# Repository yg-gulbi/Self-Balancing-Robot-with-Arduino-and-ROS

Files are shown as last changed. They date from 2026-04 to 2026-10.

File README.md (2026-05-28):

# Arduino-ROS Self-Balancing Robot

English | [한국어](README.ko.md)

This repository is my self-balancing robot project. The real robot was controlled on Arduino, and I used ROS/Gazebo for simulation, tuning, SLAM, and navigation experiments.

This is a portfolio reconstruction of the project rather than a perfectly chronological original development repository. I recovered and organized the final Arduino firmware, ROS/Gazebo workspace, hardware notes, media, CAD-related assets, results, and limitations so the project can be reviewed from evidence instead of scattered raw files.

The main result is a physical two-wheeled robot that balanced for about 1 hour and drove through a 10 m hallway and obstacle course under Arduino control. On the ROS side, I built Gazebo control, navigation, SLAM map-generation, PID tuning, and Arduino-to-ROS bridge workflows. The sim-to-real bridge is documented as a command-layer transfer: high-level motion intent is separated from the balance and safety layer instead of driving the robot directly.

## Interview Quick Read

- One-line summary: this is a two-wheeled self-balancing robot project where I isolated real hardware instability into sensor, communication, control-loop, and safety-logic problems, then stabilized the system step by step.
- My role: Arduino firmware, control algorithm design, IMU/encoder/ODrive/RC receiver integration, ROS/Gazebo simulation, SLAM/navigation workflows, and hardware debugging.
- Key debugging story: I moved away from IMU-integration-based speed estimation after finding tilt contamination, switched to wheel-encoder feedback, and added filtering/deadband/engage persistence for noisy RC PWM input. I also added current clamps and tilt cutoff so abnormal states would not become unsafe motor commands.
- Verification style: I split the system into small test paths such as `receiver_pwm_test`, `hall_sensor_test`, `odrive_receiver_test`, and `motor_current_test`, then integrated them back into the full robot.
- What to notice: the value of this project is not only the final demo, but the way unstable real hardware was made testable, safer, and repeatable.

<p align="center">
  Physical hallway balancing demo
</p>

## Result Snapshot

| Area | Result |
| --- | --- |
| Physical balance duration | About 1 hour standing balance |
| Physical driving | 10 m hallway driving and obstacle-course driving |
| Physical safety limit | Motor command cutoff at `30 deg`, chosen because the protection bracket touches the floor at about `28 deg` |
| ODrive current limit | `+/-8 A` command clamp in firmware |
| RC signal handling | `+/-50 us` deadband, throttle/steering filter alpha `0.4`, engage filter alpha `0.02` |
| Arduino-to-ROS bridge | `/imu`, `/odom`, and `cmd_vel` checked with `rostopic echo` |
| ROS/Gazebo navigation | Robot motion through the ROS navigation command path was checked and captured in the depth-navigation simulation |
| ROS/Gazebo SLAM | Map generation was checked in the SLAM workflow |

## Core Result

<p align="center">
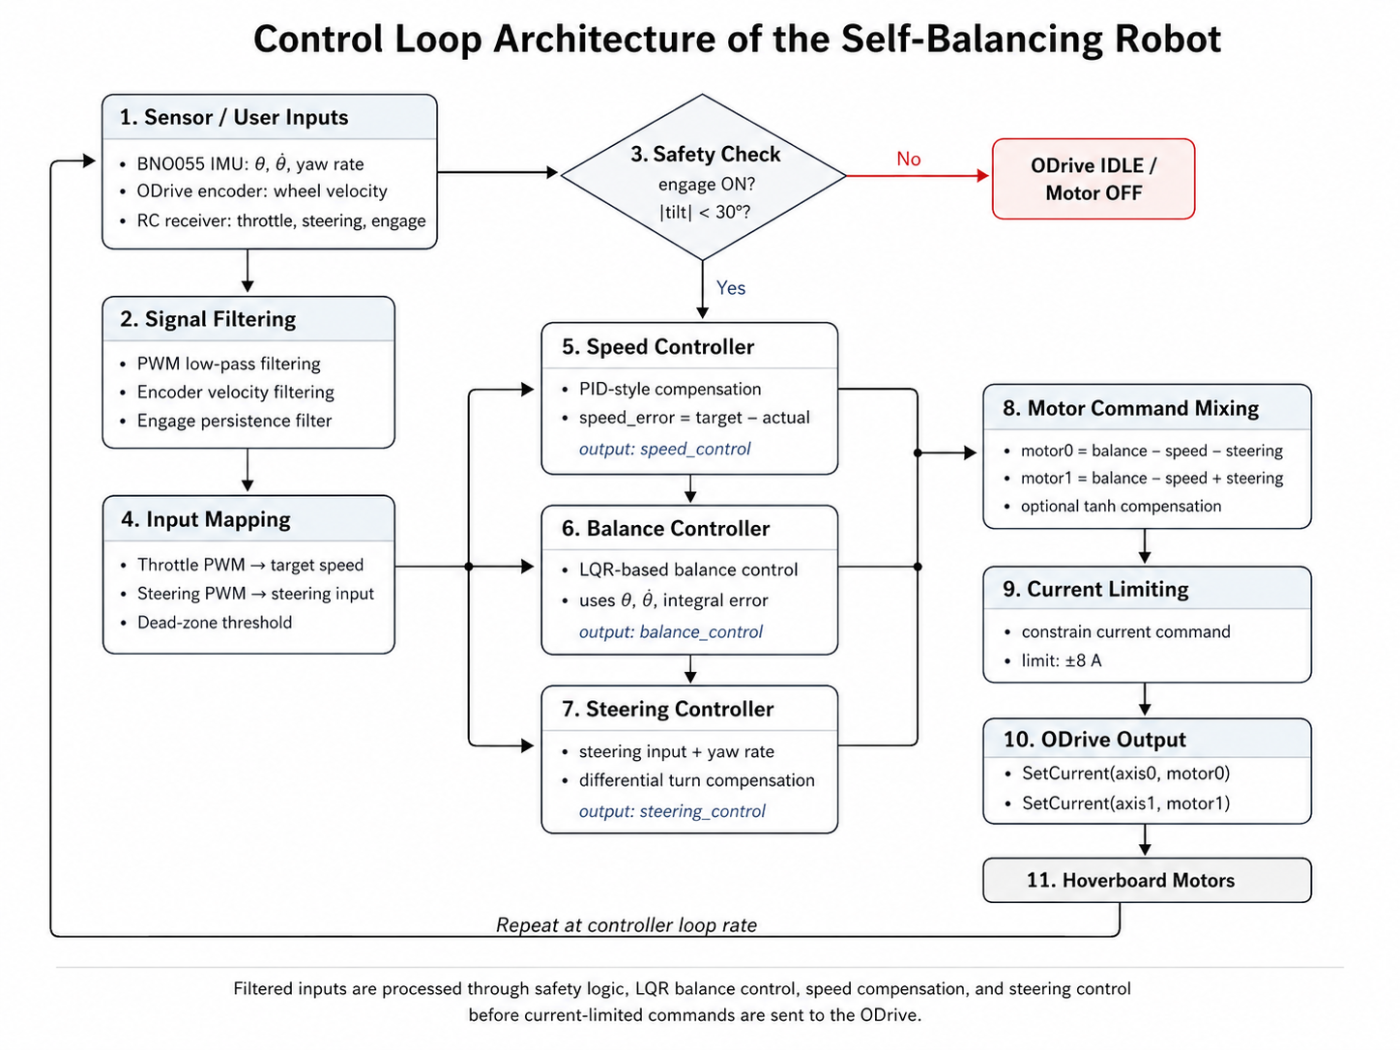
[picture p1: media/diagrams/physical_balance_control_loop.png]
Physical balance control loop
  
</p>

The Arduino closes the balance loop locally. RC intent, IMU tilt and yaw feedback, wheel-speed feedback, safety checks, and ODrive current commands are all combined into one real-time control path.

| Control layer | What it does |
| --- | --- |
| Balance | Body angle and angular velocity generate the main stabilizing current term. |
| Motion | RC throttle becomes a target speed, then shifts the balance point so the robot can drive while staying upright. |
| Safety | PWM filtering, engage persistence, tilt cutoff, and current limiting prevent bad states from reaching the motors. |

Start here: [physical balance control algorithm](firmware/physical_balance_controller/control_algorithm.md) and [troubleshooting summary](docs/troubleshooting.md).

## Project Scope

| Area | Status | Where to look |
| --- | --- | --- |
| Physical self-balancing and RC driving | Completed | [physical_balance_controller.ino](firmware/physical_balance_controller/physical_balance_controller.ino), [hallway demo](media/hero/physical_balance_hallway.gif) |
| ROS/Gazebo balance simulation | Completed | [balance_robot_control](ros_ws/src/balance_robot_control), [balance_robot_gazebo](ros_ws/src/balance_robot_gazebo) |
| Simulation navigation pipeline | Completed | [navigation](ros_ws/src/navigation), [balance_robot_workflows](ros_ws/src/balance_robot_workflows), [depth-navigation capture](media/process/simulation_depth_navigation_views.png) |
| Simulation SLAM/navigation workflow | Completed in simulation | [balance_robot_workflows](ros_ws/src/balance_robot_workflows), [results and limitations](docs/results-and-limitations.md) |
| Sim2Real bridge | Documented | [sim-to-real bridge](docs/sim2real.md), [results and limitations](docs/results-and-limitations.md) |
| Arduino-to-ROS bridge tests | Completed | [rc_to_ros_cmd_vel_bridge.ino](firmware/testers/rc_to_ros_cmd_vel_bridge.ino), [physical_balance_controller_ros.ino](firmware/physical_balance_controller_ros/physical_balance_controller_ros.ino) |
| Real-world ROS SLAM/navigation | Integration experiments | [real-world integration archive](archive/ros_experiments/real_world_integration), [results and limitations](docs/results-and-limitations.md) |

## Sim2Real Bridge

<p align="center">
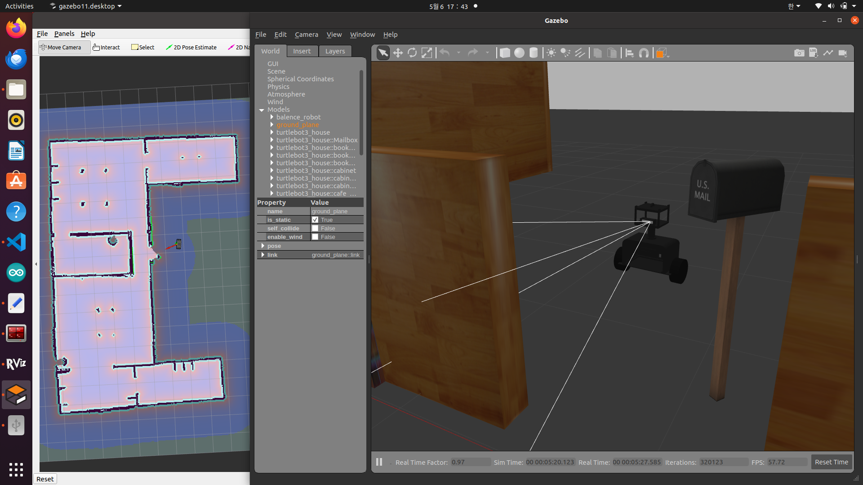
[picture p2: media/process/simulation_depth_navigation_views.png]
ROS/Gazebo depth-navigation simulation with RViz map and Gazebo robot model
  
</p>

<p align="center">
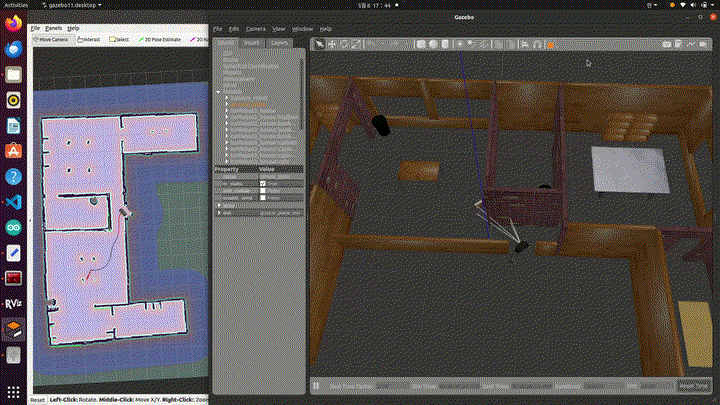
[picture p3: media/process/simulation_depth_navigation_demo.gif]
ROS/Gazebo depth-navigation simulation GIF preview
  
</p>

<p align="center">
  Full clip: <a href="media/process/simulation_depth_navigation_demo.webm">WebM download</a>
</p>

The simulation used the same two-wheeled, 3D-printed design direction as the physical robot, but the key transfer was the command structure. A high-level command is treated as motion intent first; the balance and safety layer decides what can safely reach the robot.

| Transfer point | Simulation side | Physical side |
| --- | --- | --- |
| Command path | `move_base -> /before_vel -> balance_robot_control -> /cmd_vel` | RC or ROS-side intent -> Arduino balance/safety loop -> ODrive current commands |
| Robot state | Gazebo `/imu`, `/odom`, scan/depth data, RViz map/navigation state | BNO055 IMU, ODrive feedback, RC PWM, Gemini 330 integration traces |
| What was proven | Navigation command routing, depth-navigation workflow, SLAM/map-generation workflow | Real balancing, RC driving, current limiting, tilt cutoff, and staged safety tuning |

This is why I describe the project as a sim-to-real bridge, not as finished physical autonomous navigation. The bridge is the transfer of robot design, command layering, and safety boundaries from simulation work into the real Arduino-controlled robot. See [docs/sim2real.md](docs/sim2real.md) for the detailed breakdown.

## System At A Glance

<table>
  <tr>
    <td width="50%">
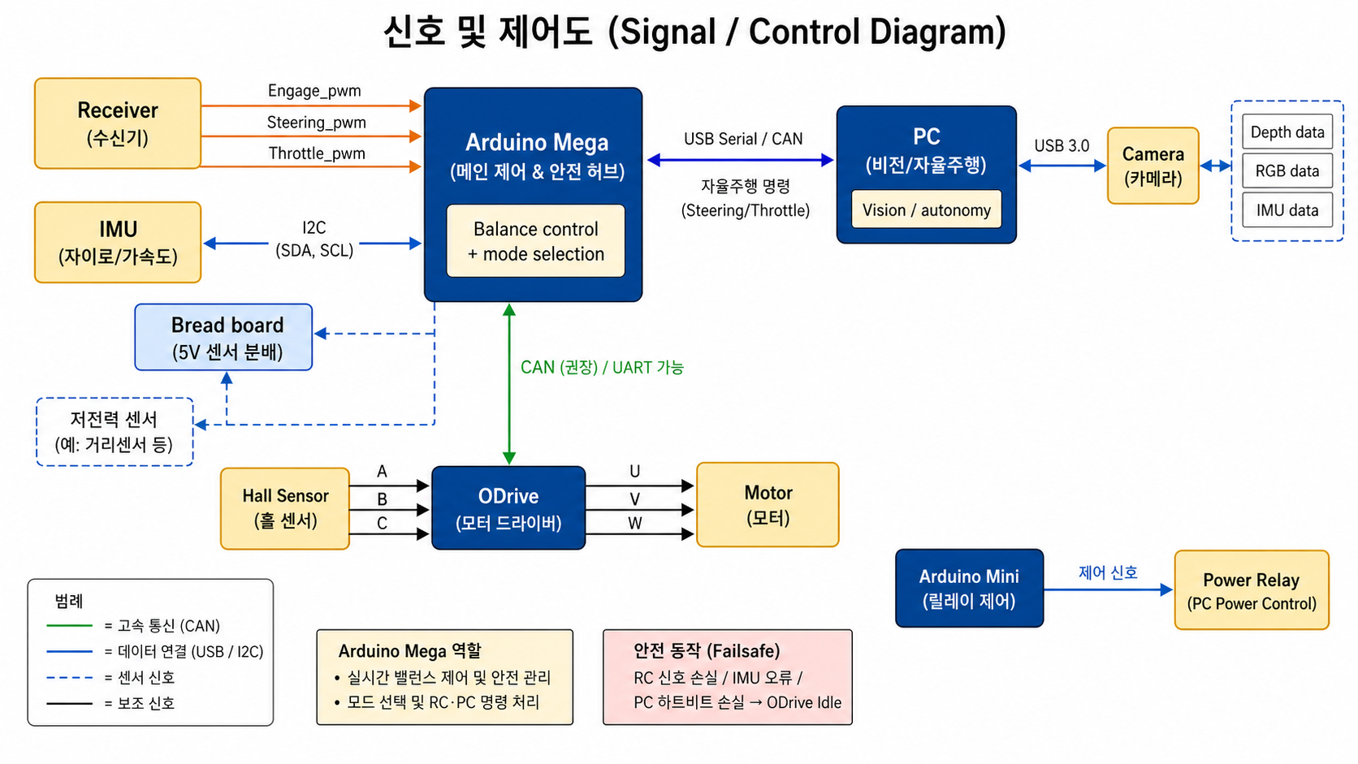
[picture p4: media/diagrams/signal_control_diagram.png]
Signal / Control Diagram
      
    </td>
    <td width="50%">
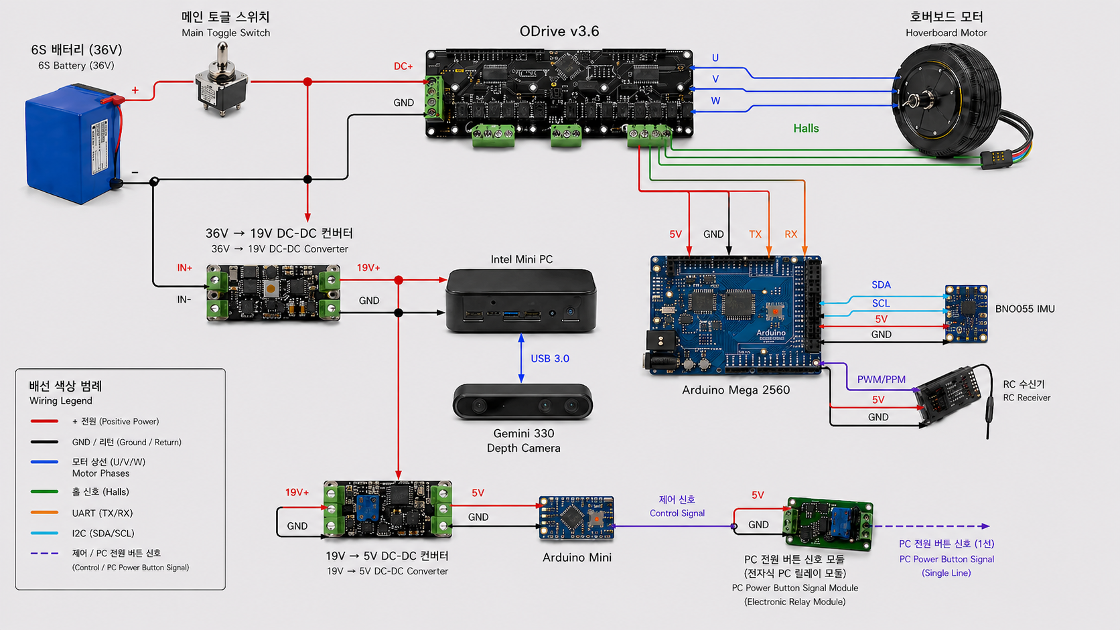
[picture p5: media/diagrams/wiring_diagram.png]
Wiring Diagram
      
    </td>
  </tr>
  <tr>
    <td valign="top">
      <strong>Control responsibility</strong><br>
      Arduino owns the real-time balance loop. ROS-side commands are treated as higher-level inputs, not direct motor authority.
    </td>
    <td valign="top">
      <strong>Hardware wiring</strong><br>
      36V power, ODrive, Arduino, BNO055, FrSky receiver, onboard PC, Gemini 330 camera, auxiliary electronics, and motors are summarized in one view.
    </td>
  </tr>
</table>

Main physical hardware: Arduino Mega 2560, BNO055 IMU, ODrive 3.6, FrSky Taranis Q X7 + X8R, Orbbec Gemini 330, dual hall-sensor BLDC hub motors, 36V battery, onboard mini PC, DC-DC converters, auxiliary Arduino, and relay module.

For the consolidated hardware explanation, see [docs/hardware.md](docs/hardware.md). For the build story and research context, see [docs/development-process.md](docs/development-process.md).

## Repository Layout

| Path | Purpose |
| --- | --- |
| `firmware/` | Arduino firmware, physical controller, and tester sketches |
| `ros_ws/` | Main ROS workspace for simulation, navigation, SLAM workflow, tuning code, and recovered actual-robot STL visuals |
| `mechanical/` | GitHub-ready 3D print, CAD, and sensor-head frame files copied from the original modeling archive |
| `docs/` | Focused portfolio docs: hardware, development process, Sim2Real, troubleshooting, and results |
| `media/` | Lightweight public GIFs, photos, and diagrams |
| `archive/` | Older experiments and recovered context that should not be the first place to read |

## Why The Title Includes Arduino And ROS

I kept `Arduino-ROS` in the title because the project really used both sides. Arduino handled the physical robot and some ROS publishing tests, while ROS/Gazebo handled simulation, visualization, SLAM and navigation workflows, and integration experiments.

| Sketch | ROS role | Published data |
| --- | --- | --- |
| [physical_balance_controller_ros.ino](firmware/physical_balance_controller_ros/physical_balance_controller_ros.ino) | ROS-enabled physical controller variant | `/imu`, `/odom` |
| [rc_to_ros_cmd_vel_bridge.ino](firmware/testers/rc_to_ros_cmd_vel_bridge.ino) | RC receiver to ROS command bridge | `cmd_vel` |
| [experimental_balance_controller_imu_ros.ino](archive/arduino_firmware/experimental_balance_controller_imu_ros.ino) | Archived IMU publisher experiment | `/imu` |
| [legacy_balance_controller.ino](archive/arduino_firmware/legacy_balance_controller.ino) | Archived ROS publisher trace | `/imu`, `/odom` publisher logic |

## ROS Workspace

This repository keeps the custom ROS packages, but it does not vendor every third-party dependency snapshot. Extra packages such as `rtabmap_ros`, `OrbbecSDK_ROS1`, `depthimage_to_laserscan`, `rosserial`, and TurtleBot3/Realsense simulation assets should be placed under `ros_ws/src/third_party/` when reproducing historical workflows.

```bash
cd ros_ws
catkin_make
source devel/setup.bash
roslaunch robot_bringup robot_remote_lidar.launch
```

Navigation-oriented simulation workflow:

```bash
roslaunch balance_robot_workflows robot_navigation_lidar.launch
```

Use [ros_ws/README.md](ros_ws/README.md) for workspace usage and [balance_robot_control/README.md](ros_ws/src/balance_robot_control/README.md) for the controller package layout.
The recovered body STL assets from the actual robot-based simulation baseline now live under [ros_ws/src/balance_robot_description/stl](ros_ws/src/balance_robot_description/stl), with notes in [docs/simulation-assets.md](docs/simulation-assets.md). The fabrication-oriented CAD and 3D-print files are organized separately in [mechanical](mechanical).

## Demo Media

- [Physical hallway balancing GIF](media/hero/physical_balance_hallway.gif)
- [Physical obstacle-course balancing GIF](media/demos/physical_balance_obstacle_course.gif)
- [ROS/Gazebo depth-navigation still](media/process/simulation_depth_navigation_views.png)
- [ROS/Gazebo depth-navigation GIF preview](media/process/simulation_depth_navigation_demo.gif)
- [ROS/Gazebo depth-navigation WebM clip](media/process/simulation_depth_navigation_demo.webm)
- [Robot-focused hallway still](media/demos/hallway_robot_only.jpg)
- [Open-front hardware photo](media/hardware/robot_open_front.png)

I did not put the full original phone MP4 files in the repo. Instead, I kept lightweight GIFs, still images, and one compact WebM simulation clip so the repository stays easier to browse. The navigation demo now includes a GitHub-friendly GIF preview plus the original WebM clip for higher-quality playback.

## Read Next

1. [Physical controller](firmware/physical_balance_controller/README.md): main Arduino firmware for the real balancing robot.
2. [Control algorithm](firmware/physical_balance_controller/control_algorithm.md): how RC input, IMU feedback, wheel speed, safety, and ODrive current control fit together.
3. [Hardware](docs/hardware.md): physical components, wiring, power flow, and layout interpretation.
4. [Mechanical 3D files](mechanical): printable frame parts, editable CAD exports, and sensor-head structure files.
5. [Development process](docs/development-process.md): build timeline, subsystem bring-up, and research decisions.
6. [Sim2Real bridge](docs/sim2real.md): how the ROS/Gazebo workflow and physical Arduino robot were connected without overstating physical autonomy.
7. [Troubleshooting summary](docs/troubleshooting.md): why filtering, safety gating, ODrive isolation, and staged tuning were needed.
8. [Results and limits](docs/results-and-limitations.md): measured project results, code-defined settings, and remaining limits.

## Limitations

- This repository is organized for portfolio review, so the commit history is not a complete record of every original hardware experiment.
- Full end-to-end autonomous ROS navigation on the physical balancing robot remains future work.
- Some older code remains in `archive/` because it still helps explain how the project evolved.
- Third-party ROS dependencies are not vendored into this repository.
- Raw process files, chat exports, and full-length videos were summarized or replaced with lighter public assets.
- Code is MIT-licensed. Media, photos, demo captures, CAD files, and 3D-print assets are included for portfolio documentation; see [LICENSE](LICENSE).

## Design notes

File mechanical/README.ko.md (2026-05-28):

# 기구 3D 파일

[English](README.md) | 한국어

이 폴더는 로봇 골격, 출력용 body part, sensor-head 구조를 GitHub에서
찾아보기 쉽게 정리한 3D 파일 모음입니다.

파일은 2026-05-11에 로컬 모델링 archive에서 가져왔습니다.

- `D:\06_3D_모델링\SLDPRT\balancing robot`
- `D:\06_3D_모델링\SLDPRT\new_balencerobot`

CAD assembly와 과거 작업 흔적을 추적하기 쉽도록 원본 파일명은 가능한 한
그대로 보존했습니다. `balanicng`, `balence`처럼 오타처럼 보이는 이름도
원본 파일명과 연결되도록 일부러 바꾸지 않았습니다.

## 폴더 역할

| 경로 | 내용 | 용도 |
| --- | --- | --- |
| `print_ready/` | main body package, side plate, board plate, battery plate, breadboard plate, Intel plate, resistor plate의 STL 및 CATPart export | 3D printing reference 및 수정 가능한 part source |
| `head_sensor_mount/` | neck, inner neck, head versions, Gemini case file(`gemini335_case`), LiDAR case의 CATIA/STL 파일 | sensor-head와 상단 frame 참고 |
| `new_balancerobot_concept/` | 작은 SolidWorks concept assembly, SLDPRT part, STL, STEP export | 이후 concept/reference geometry |

## 시각 참고 이미지

아래 eDrawings 이미지는 source CAD의 기준이 된 `balancing robot_ver4`
assembly view입니다.

<table>
  <tr>
    <td width="50%">
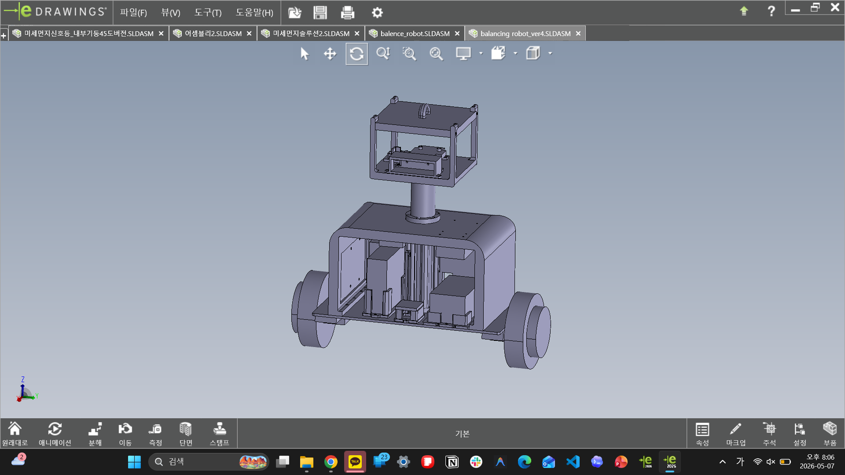
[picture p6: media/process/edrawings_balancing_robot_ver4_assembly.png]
Balancing robot ver4 eDrawings assembly view
      
    </td>
    <td width="50%">
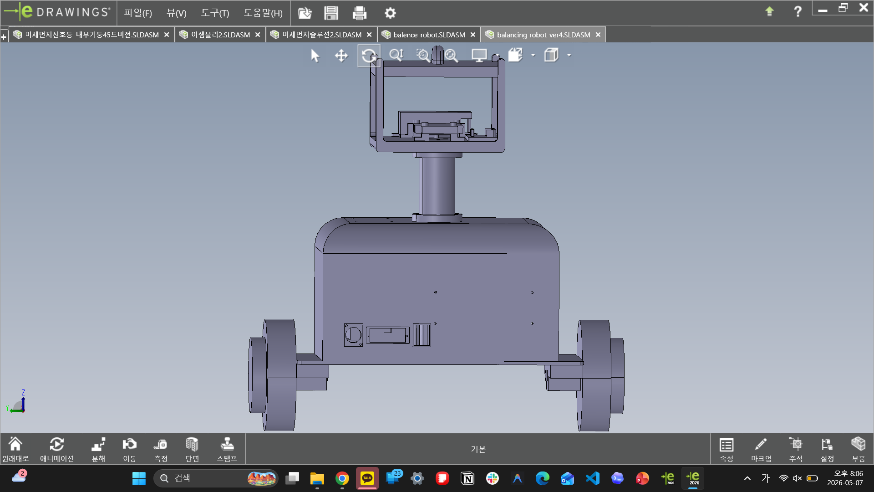
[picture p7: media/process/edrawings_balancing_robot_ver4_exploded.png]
Balancing robot ver4 eDrawings exploded view
      
    </td>
  </tr>
</table>

## ROS 모델과의 관계

현재 ROS/Gazebo package는 `ros_ws/src/balance_robot_description/stl/`의
정리된 mesh set을 사용합니다. 그쪽 파일은 URDF/Xacro에서 참조하기 쉽도록
짧은 이름으로 정리한 simulation-friendly visual asset입니다.

실제 제작용 source file이나 physical frame design을 확인할 때는 이
`mechanical/` 폴더를 보면 됩니다. URDF/Xacro visual을 수정할 때는 ROS
package 안의 `stl/` 폴더를 기준으로 보는 것이 좋습니다.

## 출력 전 메모

- 출력 전 slicer에서 scale, orientation, wall thickness, hole tolerance를
  다시 확인해야 합니다.
- 특정 printer용 G-code는 넣지 않았습니다. printer, nozzle, material,
  layer height에 맞춰 새로 생성하는 편이 안전합니다.
- 현재 ROS 모델의 collision과 inertia는 의도적으로 단순화되어 있습니다.
  이 상세 mesh를 simulation physics에 바로 넣으려면 mass, origin,
  collision assumption을 먼저 검토해야 합니다.

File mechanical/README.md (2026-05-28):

# Mechanical 3D Files

[한국어](README.ko.md) | English

This folder keeps the GitHub-facing 3D files for the robot frame, printable
body parts, and sensor-head structure.

The files were copied from the local modeling archive on 2026-05-11:

- `D:\06_3D_모델링\SLDPRT\balancing robot`
- `D:\06_3D_모델링\SLDPRT\new_balencerobot`

The original file names are preserved where possible so CAD assemblies and
historical references are easier to trace. A few misspellings such as
`balanicng` and `balence` are kept intentionally because they came from the
original project files.

## Folder Roles

| Path | Contents | Use |
| --- | --- | --- |
| `print_ready/` | STL and CATPart exports for the main body package, side plates, board plate, battery plate, breadboard plate, Intel plate, and resistor plate | 3D-print reference and editable part source |
| `head_sensor_mount/` | CATIA/STL files for the neck, inner neck, head versions, Gemini case file (`gemini335_case`), and LiDAR case | Sensor-head and upper frame reference |
| `new_balancerobot_concept/` | Smaller SolidWorks concept assembly, SLDPRT parts, STL, and STEP exports | Later concept/reference geometry |

## Visual Reference

These eDrawings views show the `balancing robot_ver4` assembly that the source
CAD files came from.

<table>
  <tr>
    <td width="50%">
      Balancing robot ver4 eDrawings assembly view
    </td>
    <td width="50%">
      Balancing robot ver4 eDrawings exploded view
    </td>
  </tr>
</table>

## How This Relates To ROS

The active ROS/Gazebo package still uses the cleaned mesh set in
`ros_ws/src/balance_robot_description/stl/`. Those files are short-name,
simulation-friendly visual assets.

Use this `mechanical/` folder when you need the fabrication-oriented source
files or want to inspect the physical frame design. Use the ROS `stl/` folder
when editing URDF/Xacro visuals.

## Printing Notes

- Re-check scale, orientation, wall thickness, and hole tolerances in your
  slicer before printing.
- No printer-specific G-code is included here. Generate fresh G-code for the
  target printer, nozzle, material, and layer height.
- Collision and inertia in the active ROS models are intentionally simplified;
  these detailed meshes should not be dropped into simulation physics without
  reviewing mass, origin, and collision assumptions.

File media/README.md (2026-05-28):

# Media

This directory stores only the media that I wanted to keep in the public repository, with cleaner filenames.

## Structure

- `hero/`: README hero asset
- `demos/`: supporting physical demo GIFs and stills
- `hardware/`: hardware photos used to support the public device story
- `process/`: build-process images such as bench tests, tethered practice, CAD screenshots, and simulation captures
- `diagrams/`: canonical GitHub-facing architecture diagrams used across the docs
- `links.md`: policy for full-length original clips

## Canonical Diagram Assets

- `diagrams/wiring_diagram.png`: main public hardware, power, and wiring overview
- `diagrams/signal_control_diagram.png`: main public control-responsibility and autonomy-flow overview
- `diagrams/physical_balance_control_loop.png`: main physical balance-control loop diagram for the Arduino firmware

## Featured Simulation Assets

- `process/simulation_depth_navigation_views.png`: public still showing RViz map/navigation state beside the Gazebo depth-camera robot model
- `process/simulation_depth_navigation_demo.webm`: compact WebM clip of the depth-navigation simulation workflow

## Featured Mechanical Assets

- `process/edrawings_balancing_robot_ver4_assembly.png`: eDrawings assembly view of the mechanical robot frame
- `process/edrawings_balancing_robot_ver4_exploded.png`: eDrawings exploded/reference view of the same assembly

## Naming Rules

- Do not store raw phone or chat-export filenames here.
- Do not store full original MP4 clips here.
- Keep only lightweight GIFs, stills, compact WebM clips, and visuals that are easy to show publicly.

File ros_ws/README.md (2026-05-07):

# ROS Workspace Guide

This folder is the main ROS workspace for the self-balancing robot project.
It shows how the simulation, balancing controller, SLAM, and navigation launch
files fit together.

The physical robot's fast balance loop runs on Arduino. In this workspace, ROS
is used for Gazebo simulation, workflow orchestration, navigation, SLAM, RViz,
and controller tuning experiments.

## Main Command Flow

The key idea is that high-level commands do not drive the balancing robot
directly.

```text
teleop or move_base
  -> /before_vel
  -> balance_robot_control
  -> /cmd_vel
  -> Gazebo robot
```

`/before_vel` is the desired motion command. The balancing controller converts
that command into a final `/cmd_vel` that respects the robot's pitch, velocity,
and steering behavior.

## Environment

This workspace targets a ROS 1 `catkin` setup, most likely Ubuntu + ROS Noetic
or a similar ROS 1 distribution.

Expected tools and packages:

- `catkin_make`
- `gazebo_ros`
- `xacro`
- `robot_state_publisher`
- `joint_state_publisher`
- `map_server`
- `amcl`
- `move_base`
- `dynamic_reconfigure`
- `rqt_reconfigure`
- `OrbbecSDK_ROS1` for physical Orbbec Gemini 330 camera integration traces
- `rtabmap_ros` or `rtabmap_launch` for depth SLAM workflows
- `depthimage_to_laserscan` for depth-camera navigation workflows
- `realsense_ros_gazebo` for historical D435-style Gazebo depth simulation assets

Third-party packages that are not part of this repository should be placed
under `src/third_party/` or installed through the normal ROS package manager.

## Build

From this folder:

```bash
cd ros_ws
catkin_make
source devel/setup.bash
```

If you open a new terminal, run `source devel/setup.bash` again before launching
anything from this workspace.

## Quick Start

These are the launch files I would start with.

| Goal | Command | Use this when |
| --- | --- | --- |
| Show the LiDAR robot model only | `roslaunch robot_bringup robot_remote_lidar.launch` | You want to inspect URDF, TF, and robot state publishing |
| Show the depth-camera robot model only | `roslaunch robot_bringup robot_remote_depth.launch` | You want to inspect the depth-camera version of the robot |
| Run LiDAR balance simulation | `roslaunch balance_robot_workflows robot_control_lidar.launch` | You want the simplest Gazebo balancing-controller demo |
| Run depth balance simulation | `roslaunch balance_robot_workflows robot_control_depth.launch` | You want the depth-camera robot model with the balancing controller |
| Tune PID gains manually | `roslaunch balance_robot_workflows robot_control_lidar_pid_tuning.launch` | You want Gazebo plus `rqt_reconfigure` for live controller tuning |
| Run LiDAR navigation simulation | `roslaunch balance_robot_workflows robot_navigation_lidar.launch` | You want map localization, `move_base`, RViz, and balance-aware command remapping |
| Run depth navigation simulation | `roslaunch balance_robot_workflows robot_navigation_depth.launch` | You want depth data projected into a scan-like navigation pipeline |
| Run depth SLAM simulation | `roslaunch balance_robot_workflows robot_slam_depth.launch` | You want the RGB-D/RTAB-Map SLAM experiment |

## Actual Robot Geometry Assets

The default model still uses the simplified box body so the historical control
and navigation setup stays unchanged. If you want the recovered STL visuals
from the actual robot-based simulation archive, add
`use_actual_stl_assembly:=true` to bringup, Gazebo, navigation, or workflow
launch commands.

Example:

```bash
roslaunch balance_robot_workflows robot_navigation_depth.launch use_actual_stl_assembly:=true
```

The STL files live in `src/balance_robot_description/stl/`. They change visual
appearance only; collision and inertia remain simple on purpose. See
[`src/balance_robot_description/README.md`](src/balance_robot_description/README.md)
and [`../docs/simulation-assets.md`](../docs/simulation-assets.md).

## Recommended Execution Order

For a first review, run the workspace in this order:

1. `roslaunch balance_robot_workflows robot_control_lidar.launch`
2. `rosrun balance_robot_control teleop_before_vel.py`
3. `roslaunch balance_robot_workflows robot_navigation_lidar.launch`
4. `roslaunch balance_robot_workflows robot_control_lidar_pid_tuning.launch`
5. `roslaunch balance_robot_workflows robot_slam_depth.launch`

Use the first command as the default control demo. Move on to navigation after the control path is working. Use PID tuning when you want to inspect gain behavior. Leave SLAM for last because it depends on the most external RGB-D packages.

## Manual Driving

For manual command testing, start a control workflow first:

```bash
roslaunch balance_robot_workflows robot_control_lidar.launch
```

Then publish desired motion into `/before_vel`. The helper script is:

```bash
rosrun balance_robot_control teleop_before_vel.py
```

The important detail is that manual teleop should target `/before_vel`, not
`/cmd_vel`. The controller owns `/cmd_vel`.

## Navigation Workflow

The navigation stack is adapted from a normal mobile-robot setup, but the output
topic is remapped.

Normal robot:

```text
move_base -> /cmd_vel
```

This balancing robot:

```text
move_base -> /before_vel -> balance_robot_control -> /cmd_vel
```

Recommended launch:

```bash
roslaunch balance_robot_workflows robot_navigation_lidar.launch
```

What this starts:

- Gazebo with the LiDAR robot model
- the balance-aware controller
- map server
- AMCL localization
- `move_base`
- RViz

In RViz, use `2D Pose Estimate` for the initial pose and `2D Nav Goal` for a
target. The planner output is routed through the balance controller before the
robot receives a final velocity command.

## SLAM Workflow

Recommended launch:

```bash
roslaunch balance_robot_workflows robot_slam_depth.launch
```

This starts the depth-camera robot workflow and RTAB-Map-related launch logic.
This path depends on external RGB-D SLAM packages, so it is the most likely
workflow to require extra package installation before it runs cleanly.

## PID Tuning Workflow

Manual tuning entrypoint:

```bash
roslaunch balance_robot_workflows robot_control_lidar_pid_tuning.launch
```

The tuning flow uses `dynamic_reconfigure`, so gains can be edited from
`rqt_reconfigure`.

The control package also keeps automated tuning experiments:

- `src/balance_robot_control/src/tuning_tools/pid_bayes_optimizer.py`
- `src/balance_robot_control/src/tuning_tools/pid_loop_test_runner.py`
- `src/balance_robot_control/src/tuning_tools/pid_reconfigure_client.py`

These scripts show that I tried repeated controller-evaluation and tuning
experiments. I do not present them as a fully solved production auto-tuning
system.

## Topic Contract

| Topic | Direction | Meaning |
| --- | --- | --- |
| `/before_vel` | input to `balance_robot_control` | Desired high-level motion from teleop or navigation |
| `/cmd_vel` | output from `balance_robot_control` | Final balance-aware command sent to the simulated robot |
| `/imu` | input to controller | Simulated robot attitude and angular velocity |
| `/odom` | input to controller/navigation | Simulated odometry feedback |
| `/scan` | input to navigation | LiDAR or depth-projected scan data |
| `/map` | input to navigation/RViz | Static map from `map_server` or SLAM output |

## Package Map

| Folder | ROS package name | Role |
| --- | --- | --- |
| `src/balance_robot_bringup/` | `robot_bringup` | Robot model bringup and description launch entrypoints |
| `src/balance_robot_description/` | `robot_description` | URDF/Xacro definitions plus recovered actual-robot STL body visuals |
| `src/balance_robot_gazebo/` | `robot_gazebo` | Gazebo worlds, robot spawn files, and controller launch files |
| `src/balance_robot_control/` | `balance_robot_control` | Balance-aware control nodes, PID tuning, and tuning automation helpers |
| `src/balance_robot_workflows/` | `balance_robot_workflows` | Scenario-level launch files for control, tuning, navigation, and SLAM |
| `src/navigation/` | `navigation` | `move_base`, AMCL, maps, planner parameters, and RViz configs |
| `src/third_party/` | external packages | Optional location for dependencies not committed to this repo |

## If You Want To Read The ROS Side Quickly

I would read the ROS side in this order:

1. [`src/balance_robot_workflows/README.md`](src/balance_robot_workflows/README.md)
2. [`src/balance_robot_control/README.md`](src/balance_robot_control/README.md)
3. [`src/balance_robot_description/README.md`](src/balance_robot_description/README.md)
4. [`src/navigation/README.md`](src/navigation/README.md)
5. [`../docs/results-and-limitations.md`](../docs/results-and-limitations.md)

## Troubleshooting

If a package cannot be found, source the workspace again:

```bash
source devel/setup.bash
rospack find balance_robot_control
```

If Gazebo opens but the robot does not move, check that the controller is
running and that `/before_vel` is receiving commands:

```bash
rostopic list
rostopic echo /before_vel
rostopic echo /cmd_vel
rosnode list
```

If navigation does not move the robot, confirm that `move_base` is publishing
to `/before_vel` and that `balance_robot_control` is republishing to `/cmd_vel`.

If SLAM launch fails, install or provide the missing RGB-D packages first. The
most likely missing packages are `rtabmap_ros`, `rtabmap_launch`, camera plugin
packages, or depth-to-scan conversion packages.

## Scope And Limits

- This workspace is strongest on the simulation and integration side.
- The real physical balance loop was implemented on Arduino firmware, not ROS.
- Physical camera, TF, and SLAM integration traces are preserved mainly in
  [`../archive/ros_experiments/real_world_integration`](../archive/ros_experiments/real_world_integration/README.md).
- Historical workspace-name mapping is preserved in
  [`../archive/ros_experiments/workspace_history.md`](../archive/ros_experiments/workspace_history.md).
- End-to-end autonomous navigation on the physical balancing robot is not
  presented as fully finished in this repository.

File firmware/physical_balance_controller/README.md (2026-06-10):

# Physical Balance Controller

This folder contains the main physical robot controller for the repository.

- Main file: [`physical_balance_controller.ino`](physical_balance_controller.ino)
- ROS-enabled variant: [`../physical_balance_controller_ros`](../physical_balance_controller_ros)
- Control structure: [`control_algorithm.md`](control_algorithm.md)
- Purpose: real-world balancing and RC driving on Arduino using BNO055 and ODrive

Why this file is the main controller:

- It is the clearest standalone physical robot balancing implementation in the archive.
- It keeps the balancing and drive loop on Arduino rather than requiring ROS in the low-level loop.
- It best matches the actual completed physical robot behavior shown in this repository.

## What The Controller Does

At a high level, the controller combines:

- RC PWM input for throttle, steering, and motor engage
- BNO055 tilt angle, angular velocity, and yaw-rate feedback
- ODrive wheel-speed feedback
- body-angle balance correction, PID-like speed correction, and steering correction
- motor safety gates, tilt cutoff, current limiting, and serial gain tuning

See [`control_algorithm.md`](control_algorithm.md) for the GitHub-friendly algorithm diagram and control-flow explanation.

If ROS state publishing is needed, use the separate [`physical_balance_controller_ros`](../physical_balance_controller_ros) sketch. It keeps the same Arduino-side balancing structure but adds `rosserial` publishers for `/imu` and `/odom`.

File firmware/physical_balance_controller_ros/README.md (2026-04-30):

# Physical Balance Controller + ROS

This sketch is a ROS-enabled variant of the main physical balancing controller.

- Main file: [`physical_balance_controller_ros.ino`](physical_balance_controller_ros.ino)
- Base controller: [`../physical_balance_controller/physical_balance_controller.ino`](../physical_balance_controller/physical_balance_controller.ino)
- Archived ROS source: [`../../archive/arduino_firmware/legacy_balance_controller.ino`](../../archive/arduino_firmware/legacy_balance_controller.ino)

## Purpose

The original physical controller keeps the real-time balance loop fully on Arduino for safety and timing. This variant keeps that architecture, then adds the archived `rosserial` publishing path so the physical robot can expose state to ROS:

| Topic | Message | Source |
| --- | --- | --- |
| `/imu` | `sensor_msgs/Imu` | BNO055 orientation, gyro, and linear acceleration |
| `/odom` | `nav_msgs/Odometry` | Integrated wheel-speed odometry from ODrive feedback |

## Control And Communication Structure

The important design choice is that ROS does not close the balance loop. Arduino still performs:

- RC PWM decoding for throttle, steering, and engage
- IMU tilt feedback and tilt cutoff
- wheel-speed feedback from ODrive
- balance correction, speed correction, steering correction, and current limiting
- ODrive closed-loop state switching and current commands

ROS receives state for visualization, logging, mapping, or higher-level integration. This avoids depending on USB/ROS timing for the unstable balancing loop.

## Usage

Upload this sketch instead of the non-ROS physical controller when you want ROS state topics:

```bash
roscore
rosrun rosserial_python serial_node.py _port:=/dev/ttyACM0 _baud:=115200
rostopic echo /imu
rostopic echo /odom
```

Adjust `/dev/ttyACM0` to the Arduino port on your machine.

## Notes

- `Serial` is owned by `rosserial` in this variant. Avoid normal `Serial.print()` debugging while connected to ROS because it can corrupt the rosserial frame stream.
- The serial gain-tuning command processor is left in the code but disabled by default with `kSerialGainTuningEnabled = false`.
- `/odom` is wheel-speed integration, so it will drift over time. It is useful as a ROS integration signal, not as a globally accurate pose estimate.

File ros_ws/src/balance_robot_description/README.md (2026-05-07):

# Robot Description Package

This package keeps the active URDF/Xacro files for the balancing robot and the
recovered STL body parts that came from the actual robot-based simulation
archive.

## Folder Roles

- `urdf/`: active LiDAR and depth-camera robot models used by launch files
- `stl/`: recovered body-part visuals copied from the 2026-05-07 archive export

## Visual Modes

By default, the robot body stays a simple box. That keeps the historical
simulation behavior, collision volumes, and inertia assumptions stable.

If you want the recovered actual-robot body visuals, launch with:

```bash
roslaunch robot_bringup robot_remote_depth.launch use_actual_stl_assembly:=true
```

or:

```bash
roslaunch balance_robot_workflows robot_navigation_lidar.launch use_actual_stl_assembly:=true
```

`use_actual_stl_assembly:=true` switches the `base_link` visuals to the
multi-part STL assembly in `stl/`, but collision and inertia stay simple on
purpose.

## Notes

- The STL placement transform comes from the archived simulation workspace
  that was derived from the physical robot.
- The archive also referenced a single-file `meshes/base_body.stl`, but that
  mesh was not recovered here. The tracked GitHub baseline is the multi-part
  `stl/` assembly instead.
- For the archive provenance and the frame-position notes worth reviewing
  before changing simulation code, see `../../../docs/simulation-assets.md`.

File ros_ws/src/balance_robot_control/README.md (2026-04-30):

# balance_robot_control

This package is the cleaned ROS control package for the current `ros_ws`
simulation stack.

Its core idea is simple but unusual:

1. accept a desired motion command on `/before_vel`,
2. estimate how much the robot must lean to satisfy that request,
3. combine balance correction and steering correction,
4. publish the final low-level command on `/cmd_vel`.

That makes this package the center of the balancing simulation stack.

## Package Role

- consumes `/before_vel`, `/imu`, and `/odom`
- produces `/cmd_vel`
- inserts a balancing layer between navigation and the robot base
- stores both manual tuning and automatic tuning experiments
- keeps the depth-model and LiDAR-model control variants in one package

The most important system-level consequence is that `move_base` does not command the robot directly. Instead:

`move_base -> /before_vel -> balance_robot_control -> /cmd_vel`

The name `balance_robot_control` was chosen because this package contains more
than one controller script. It includes the main balance-aware control nodes,
the depth and LiDAR variants, the PID tuning entrypoints, and helper scripts
such as Bayesian optimization and repeated-loop evaluation.

## Source Layout

| Folder | Purpose |
| --- | --- |
| `src/controllers/` | Main balance controllers used during normal LiDAR or depth simulation |
| `src/tuning_controllers/` | Controller variants that expose tuning hooks such as `dynamic_reconfigure` or `/setpoint_angle` |
| `src/tuning_tools/` | Outer-loop tuning, repeated test, and reconfigure helper scripts |
| `src/utils/` | Small support utilities such as Gazebo reset and `/before_vel` teleop |

`CMakeLists.txt` installs these Python scripts with `catkin_install_python`, so launch files can still reference the executable filename directly.

## File-by-File Guide

### Active controller files

#### [`cfg/PID.cfg`](cfg/PID.cfg)

Defines the `dynamic_reconfigure` parameters used by the tuning variants:

- `Kp_angle`
- `Kd_angle`
- `Kp_speed`
- `Kp_steering`
- `Kd_steering`

This file does not run by itself. It generates the Python config class that the tuning nodes import.

#### [`src/controllers/pid_control_before_vel_lidar.py`](src/controllers/pid_control_before_vel_lidar.py)

Main LiDAR-version balancing controller.

What it does:

- subscribes to `/before_vel`, `/imu`, and `/odom`
- converts speed error into a desired lean angle
- computes pitch-rate and roll-rate from quaternion differences
- publishes final motion on `/cmd_vel`
- stops the robot if pitch exceeds about 40 degrees

Why it matters:

- this is the main expression of the balancing architecture
- it is the default controller for LiDAR-based simulation

#### [`src/controllers/pid_control_before_vel_depth.py`](src/controllers/pid_control_before_vel_depth.py)

Depth-camera version of the same controller.

What is different from the LiDAR version:

- higher pitch gains
- steering gains are slightly different
- desired lean angle is clamped to about +/-30 degrees
- an extra pitch bias term is applied in the angle error

Interpretation:

- the controller structure stayed the same
- the depth-camera simulation needed different gains and a small posture offset compensation

#### [`src/tuning_controllers/pid_control_before_vel_lidar_pid_tuning.py`](src/tuning_controllers/pid_control_before_vel_lidar_pid_tuning.py)

LiDAR controller variant used for manual PID tuning.

What it adds:

- `dynamic_reconfigure` server
- runtime PID gain edits from `rqt_reconfigure`
- simulation reset detection
- state reinitialization when Gazebo time jumps backward

Why it exists:

- Gazebo reset behavior interfered with controller tuning
- this version was built specifically to survive repeated reset-and-retest workflows

#### [`src/tuning_controllers/pid_control_before_vel_lidar_pid_auto_tuning.py`](src/tuning_controllers/pid_control_before_vel_lidar_pid_auto_tuning.py)

Controller variant prepared for automated tuning.

What it adds beyond the manual tuning version:

- publishes `/setpoint_angle`
- remains `dynamic_reconfigure` compatible
- is designed to be scored by an outer optimization loop

Why `/setpoint_angle` matters:

- the optimizer can compare the commanded lean target with the actual pitch response
- that makes balance-tracking quality measurable instead of only visually judged

### Tuning and automation helpers

#### [`src/tuning_tools/pid_bayes_optimizer.py`](src/tuning_tools/pid_bayes_optimizer.py)

Bayesian optimization driver for LiDAR PID tuning.

What it does:

- updates PID values through `dynamic_reconfigure`
- resets Gazebo using ROS services
- runs a repeatable motion sequence: stop -> forward/turn -> stop
- subscribes to `/imu`, `/odom`, and `/setpoint_angle`
- computes a score from tracking, stopping, balance, and angular errors
- applies a heavy penalty if the robot falls

Why it matters:

- this file shows the project went beyond controller implementation into tuning automation
- it is one of the clearest signs that repeated evaluation and optimization were attempted systematically

#### [`src/tuning_tools/pid_loop_test_runner.py`](src/tuning_tools/pid_loop_test_runner.py)

Simpler repeat-test runner for a fixed PID set.

What it does:

- reconfigures the controller
- pauses/resets/unpauses Gazebo
- commands forward motion
- repeats the same loop 100 times

Why it exists:

- this is a lighter-weight precursor to the full Bayesian optimizer
- it helped check whether a candidate PID configuration could survive repeated reset cycles

#### [`src/utils/gazebo_reset_world.py`](src/utils/gazebo_reset_world.py)

Small Gazebo utility script.

What it does:

- pause physics
- reset world
- wait briefly
- unpause physics

Why it exists:

- controller tuning and loop testing needed a repeatable reset helper

#### [`src/tuning_tools/pid_reconfigure_client.py`](src/tuning_tools/pid_reconfigure_client.py)

Minimal `dynamic_reconfigure` client example.

What it does:

- connects to the PID tuning node
- updates selected PID parameters programmatically

Why it exists:

- proves the tuning node can be controlled from code, not only from `rqt_reconfigure`

### Command input helper

#### [`src/utils/teleop_before_vel.py`](src/utils/teleop_before_vel.py)

Keyboard teleoperation publisher for `/before_vel`.

Why it matters:

- the balancing controller expects desired motion on `/before_vel`
- this file provides a manual way to drive the balance stack without navigation

## Archived Experiment Lineage

Earlier controller variants were intentionally moved to [archive/ros_experiments/pid_experiments](../../../archive/ros_experiments/pid_experiments/README.md).

Those files preserve the path from rough experiments to the cleaned package above:

- [`pid_control_cmd_vel.py`](../../../archive/ros_experiments/pid_experiments/pid_control_cmd_vel.py): earliest command path, before `/before_vel` became standard
- [`pid_control_before_vel.py`](../../../archive/ros_experiments/pid_experiments/pid_control_before_vel.py): early `/before_vel` controller without odometry-based speed feedback
- [`pid_control_before_vel_odom.py`](../../../archive/ros_experiments/pid_experiments/pid_control_before_vel_odom.py): early controller that uses `/odom` speed feedback
- [`pid_control_before_vel_odom_vel.py`](../../../archive/ros_experiments/pid_experiments/pid_control_before_vel_odom_vel.py): transition experiment mixing angle control and speed-estimation ideas
- [`pid_control_before_vel_revised.py`](../../../archive/ros_experiments/pid_experiments/pid_control_before_vel_revised.py): experiment that integrates IMU linear acceleration to estimate speed

These files are useful historically because they show the control-design progression:

1. direct command experiments,
2. `/before_vel` adoption,
3. speed-feedback experiments,
4. tuning automation.

## Known Boundaries

- These controllers operate in simulation and assume `/imu` and `/odom` already exist.
- The LiDAR and depth variants are tuned separately rather than abstracted into one generic controller.
- `dynamic_reconfigure` and Bayesian tuning were explored, but I do not present automated tuning as fully solved.
- Many script filenames still reflect the original PID-experiment history even though the package itself was renamed to `balance_robot_control`.

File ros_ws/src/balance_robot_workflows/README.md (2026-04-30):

# balance_robot_workflows

This package is the workflow-orchestration layer for the simulation workspace.
It does not own the balancing equation itself. Instead, it decides which
combination of robot model, sensor setup, and higher-level stack should run.

In practice, it answers questions like:

- "spawn the balancing robot with LiDAR and run normal control"
- "spawn the balancing robot with a depth camera and run navigation"
- "spawn the depth model and launch RTAB-Map SLAM"
- "start the PID-tuning workflow instead of the normal driving workflow"

## Package Role

- bundles lower-level packages into reusable launch entrypoints
- chooses among `LiDAR`, `depth`, and controller-tuning scenarios
- keeps control, navigation, and SLAM flows separate by use case
- exposes the main entrypoints for control, navigation, SLAM, and tuning

## Launch Files

### [`launch/robot_control_lidar.launch`](launch/robot_control_lidar.launch)

Starts the LiDAR-based balancing simulation by including the Gazebo launch from `robot_gazebo`.

This is the simplest "controller only" LiDAR entrypoint.

### [`launch/robot_control_depth.launch`](launch/robot_control_depth.launch)

Starts the depth-camera-based balancing simulation by including the Gazebo depth launch.

This is the depth counterpart to the LiDAR control-only workflow.

### [`launch/robot_control_lidar_pid_tuning.launch`](launch/robot_control_lidar_pid_tuning.launch)

Starts the LiDAR tuning setup and also launches `rqt_reconfigure`.

This is the manual tuning entrypoint when changing PID values live.

### [`launch/robot_navigation_lidar.launch`](launch/robot_navigation_lidar.launch)

Starts:

- Gazebo LiDAR simulation
- the balancing controller
- the navigation stack

This is the main LiDAR navigation integration launch.

### [`launch/robot_navigation_depth.launch`](launch/robot_navigation_depth.launch)

Starts:

- Gazebo depth simulation
- `depthimage_to_laserscan`
- the navigation stack

Important note:

- the navigation package itself expects a `scan` topic
- this launch is where depth-camera data is projected into a 2D laser-like scan before navigation uses it

### [`launch/robot_slam_depth.launch`](launch/robot_slam_depth.launch)

Starts the depth-camera SLAM flow in simulation.

Main pieces:

- Gazebo depth simulation
- `joint_state_publisher`
- `robot_state_publisher`
- RTAB-Map launch

This is the main RGB-D SLAM simulation entrypoint in the cleaned repository.

## How It Relates to Other Packages

- `balance_robot_workflows` decides **which workflow** to run.
- `balance_robot_control` contains the actual balancing-controller logic.
- `robot_gazebo` starts the correct simulation world and robot model.
- `navigation` contains `move_base`, AMCL, maps, and planner configs.

So the package split is:

- `balance_robot_workflows`: orchestration
- `balance_robot_control`: controller implementation
- `navigation`: planner/localization stack

## Why This Package Exists

The original archive had many launch files scattered across several packages and workspaces. This package keeps the cleaned repository easier to read by giving each common workflow a named entrypoint.

The name `balance_robot_workflows` was chosen because this package is really a
scenario selector. It is where the repo decides whether the balancing robot is
spawned with LiDAR, with a depth camera, for controller-only driving, for
manual PID tuning, for navigation, or for depth SLAM.

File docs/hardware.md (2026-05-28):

# Hardware

English | [한국어](ko/hardware.md)

This page is the single hardware reference for the physical self-balancing robot. It combines the previous BOM, power/IO notes, layout interpretation, and gallery material so people do not have to jump across several small hardware documents.

<table>
  <tr>
    <td width="38%">
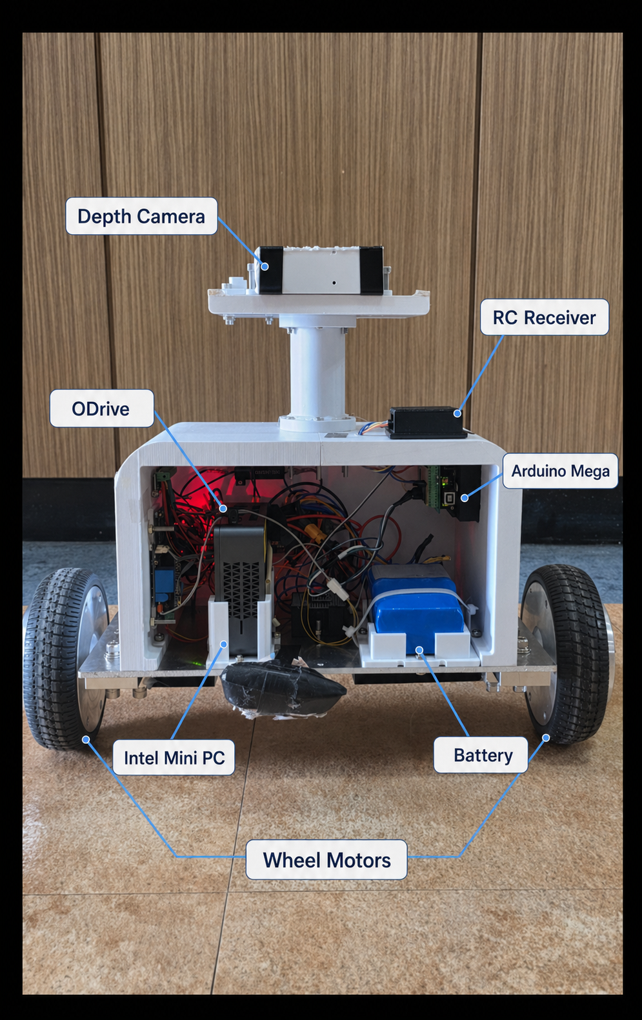
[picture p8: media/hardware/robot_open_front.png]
Internal hardware photo
      
    </td>
    <td width="62%">
      Wiring Diagram
    </td>
  </tr>
  <tr>
    <td valign="top">
      <strong>Physical layout</strong><br>
      Real chassis, sensor head, electronics bay, battery area, compute enclosure, and wheel base.
    </td>
    <td valign="top">
      <strong>System wiring summary</strong><br>
      Power chain, Arduino, BNO055, FrSky receiver, ODrive, motors, onboard PC, Gemini 330, auxiliary Arduino, and relay path.
    </td>
  </tr>
</table>

## Confirmed Components

| Component | Identification | Role |
| --- | --- | --- |
| Main controller | Arduino Mega 2560 | Runs the physical balance, RC input, safety, and ODrive command loop |
| IMU | BNO055 | Body angle and gyro feedback for balancing |
| Motor controller | ODrive 3.6 | Current-based dual-motor control |
| Depth camera | Orbbec Gemini 330 | Upper sensor-head perception hardware for ROS integration experiments |
| RC transmitter | FrSky 2.4GHz Taranis Q X7 | Handheld throttle, steering, and engage control |
| RC receiver | FrSky X8R | PWM command input into Arduino |

## Best-Effort Hardware Identification

Some exact part numbers were not retained, so these are described conservatively from firmware, wiring diagrams, photos, and process material.

| Subsystem | Best-effort identification | Why I think so |
| --- | --- | --- |
| Wheels and motors | Dual 36V hall-sensor BLDC hub motors, likely hoverboard-style, roughly 165 mm wheel diameter | Firmware uses hall feedback and about `0.0825 m` wheel radius; photos match hub-wheel assemblies |
| Battery | 36V battery pack, likely lithium-ion | Wiring diagram and internal photo both show a 36V system bus |
| Power conversion | 36V -> 19V and 19V -> 5V DC-DC converters | Wiring diagram shows compute and low-voltage control rails |
| Onboard compute | 19V mini PC, likely x86/NUC-class | Wiring diagram labels a PC rail; internal photo shows a vented compute enclosure |
| Auxiliary controller | Arduino Mini/Nano-class board | Wiring diagram labels a mini Arduino on the 5V side |
| Relay path | 5V relay or switching module | Wiring diagram shows an auxiliary relay/power-relay block |
| Chassis | 3D-printed body, mast, and sensor-head mount on a metal base plate | CAD/process images and physical photos support a purpose-built enclosure |

The GitHub-ready frame, printable STL, CATPart, STEP, and SolidWorks concept
files are collected in [mechanical](../mechanical). The ROS package keeps a
separate short-name STL set for simulation visuals.

## Power And Signal Flow

```text
36V Battery
  -> ODrive 3.6 -> dual wheel motors
  -> 36V->19V converter -> onboard PC
  -> 19V->5V converter -> auxiliary Arduino / relay module

FrSky Taranis Q X7 -> FrSky X8R receiver -> Arduino Mega 2560
BNO055 IMU -> Arduino Mega 2560
Arduino Mega 2560 -> ODrive 3.6 command path
Orbbec Gemini 330 -> onboard PC
```

The physical control path is intentionally simple: `FrSky receiver + BNO055 -> Arduino -> ODrive -> motors`. ROS and perception hardware sit above that layer and are not required for the real-time balancing loop.

## Layout Interpretation

The public photo is left mostly unannotated because earlier direct callouts risked over-identifying parts. The reliable visible zones are:

- upper Orbbec Gemini 330 sensor-head area
- left-side auxiliary board area
- central compute and wiring bay
- right-side 36V battery pack
- open front service area exposing the internal electronics

## Historical Camera Naming Note

Some simulation-side URDF and launch files still reference `RealSense D435` assets or `d435` topic names. Those belong to historical simulation or placeholder RGB-D workflows. The deployed physical camera documented here is the Orbbec Gemini 330.

## Limits Of This Page

- The Wiring Diagram is a high-level project diagram, not a manufacturing schematic.
- Wire colors, connector pinouts, regulator part numbers, and exact battery chemistry should not be inferred beyond what is visible in the material.
- This page is written for portfolio review and system understanding, not as a complete rebuild guide.

## Supporting Images

| Asset | Why it matters |
| --- | --- |
| [Wiring Diagram](../media/diagrams/wiring_diagram.png) | Main hardware, power, and wiring overview |
| [Open-front robot photo](../media/hardware/robot_open_front.png) | Real electronics packaging and sensor-head layout |
| [Wheel bench test](../media/process/wheel_bench_test.jpg) | Motor, wheel, and controller bring-up before full-body balancing |
| [Tethered driving practice](../media/process/tethered_driving_practice.jpg) | Safety-supported physical tuning stage |

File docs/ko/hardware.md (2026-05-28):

# 하드웨어

[English](../hardware.md) | 한국어

이 문서는 실제 셀프 밸런싱 로봇의 단일 하드웨어 reference입니다. 기존 BOM, power/IO notes, layout interpretation, gallery material을 하나로 합쳐서 여러 작은 문서를 오갈 필요가 없게 했습니다.

<table>
  <tr>
    <td width="38%">
      Internal hardware photo
    </td>
    <td width="62%">
      Wiring Diagram
    </td>
  </tr>
  <tr>
    <td valign="top">
      <strong>Physical layout</strong><br>
      실제 chassis, sensor head, electronics bay, battery area, compute enclosure, wheel base입니다.
    </td>
    <td valign="top">
      <strong>System wiring summary</strong><br>
      Power chain, Arduino, BNO055, FrSky receiver, ODrive, motors, onboard PC, Gemini 330, auxiliary Arduino, relay path를 요약합니다.
    </td>
  </tr>
</table>

## 확인된 구성품

| Component | Identification | Role |
| --- | --- | --- |
| Main controller | Arduino Mega 2560 | 실제 balance, RC input, safety, ODrive command loop 실행 |
| IMU | BNO055 | 균형 제어를 위한 body angle 및 gyro feedback |
| Motor controller | ODrive 3.6 | Current-based dual-motor control |
| Depth camera | Orbbec Gemini 330 | ROS integration experiment를 위한 상단 sensor-head perception hardware |
| RC transmitter | FrSky 2.4GHz Taranis Q X7 | Handheld throttle, steering, engage control |
| RC receiver | FrSky X8R | Arduino로 들어가는 PWM command input |

## 보수적인 하드웨어 식별

일부 정확한 part number는 남아 있지 않기 때문에, firmware, wiring diagram, photo, process material을 바탕으로 보수적으로 설명했습니다.

| Subsystem | Best-effort identification | Why I think so |
| --- | --- | --- |
| Wheels and motors | Dual 36V hall-sensor BLDC hub motors, hoverboard-style 가능성이 높고 wheel diameter는 약 165 mm | Firmware가 hall feedback과 약 `0.0825 m` wheel radius를 사용하며, 사진도 hub-wheel assembly와 맞습니다 |
| Battery | 36V battery pack, lithium-ion 가능성이 높음 | Wiring diagram과 internal photo 모두 36V system bus를 보여줍니다 |
| Power conversion | 36V -> 19V 및 19V -> 5V DC-DC converters | Wiring diagram에 compute rail과 low-voltage control rail이 표시되어 있습니다 |
| Onboard compute | 19V mini PC, x86/NUC-class 가능성이 높음 | Wiring diagram에 PC rail이 있고, internal photo에 vented compute enclosure가 보입니다 |
| Auxiliary controller | Arduino Mini/Nano-class board | Wiring diagram에 5V side mini Arduino가 표시되어 있습니다 |
| Relay path | 5V relay 또는 switching module | Wiring diagram에 auxiliary relay/power-relay block이 보입니다 |
| Chassis | Metal base plate 위의 3D-printed body, mast, sensor-head mount | CAD/process image와 실제 사진이 purpose-built enclosure를 뒷받침합니다 |

GitHub에서 확인하기 쉬운 frame, printable STL, CATPart, STEP, SolidWorks
concept file은 [mechanical](../../mechanical)에 모았습니다. ROS package에는
simulation visual용으로 짧은 이름의 STL set을 따로 유지합니다.

## Power And Signal Flow

```text
36V Battery
  -> ODrive 3.6 -> dual wheel motors
  -> 36V->19V converter -> onboard PC
  -> 19V->5V converter -> auxiliary Arduino / relay module

FrSky Taranis Q X7 -> FrSky X8R receiver -> Arduino Mega 2560
BNO055 IMU -> Arduino Mega 2560
Arduino Mega 2560 -> ODrive 3.6 command path
Orbbec Gemini 330 -> onboard PC
```

실제 control path는 의도적으로 단순하게 유지했습니다: `FrSky receiver + BNO055 -> Arduino -> ODrive -> motors`. ROS와 perception hardware는 그 위 계층에 있으며, 실시간 balancing loop에는 필수 요소가 아닙니다.

## Layout Interpretation

공개 사진에는 직접적인 callout을 많이 넣지 않았습니다. 이전의 직접 라벨링은 부품을 과하게 특정할 위험이 있었기 때문입니다. 비교적 신뢰할 수 있는 visible zone은 다음과 같습니다.

- upper Orbbec Gemini 330 sensor-head area
- left-side auxiliary board area
- central compute and wiring bay
- right-side 36V battery pack
- internal electronics가 보이는 open front service area

## Historical Camera Naming Note

일부 simulation-side URDF와 launch file은 아직 `RealSense D435` asset이나 `d435` topic name을 참조합니다. 이것들은 historical simulation 또는 placeholder RGB-D workflow에 속합니다. 이 문서에서 실제 deployed physical camera로 기록하는 장비는 Orbbec Gemini 330입니다.

## 이 문서의 한계

- Wiring Diagram은 high-level project diagram이지 manufacturing schematic이 아닙니다.
- Wire color, connector pinout, regulator part number, 정확한 battery chemistry는 보이는 자료 이상으로 추정하지 않았습니다.
- 이 문서는 portfolio review와 system understanding을 위한 문서이며, 완전한 rebuild guide는 아닙니다.

## Supporting Images

| Asset | Why it matters |
| --- | --- |
| [Wiring Diagram](../../media/diagrams/wiring_diagram.png) | 주요 hardware, power, wiring overview |
| [Open-front robot photo](../../media/hardware/robot_open_front.png) | 실제 electronics packaging과 sensor-head layout |
| [Wheel bench test](../../media/process/wheel_bench_test.jpg) | full-body balancing 이전의 motor, wheel, controller bring-up |
| [Tethered driving practice](../../media/process/tethered_driving_practice.jpg) | 안전 지지 상태에서 진행한 physical tuning stage |

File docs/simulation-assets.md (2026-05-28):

# Simulation Asset Baseline

This note records the actual robot-derived geometry assets that were recovered
while preparing the repository for GitHub.

## Source Archive

The recovered files came from the workspace archive:

- `archive_sources/legacy_workspace_archive/exported_balance_robot_stl_changes_20260507`

That archive contained:

- `stl/`: body-part STL exports
- `urdf/balence_robot_urdf.xacro`
- `urdf/balence_robot_urdf_depth.xacro`
- supporting README notes about missing single-mesh placeholders

## What Was Moved Into The Repo

The GitHub-facing package is:

- `ros_ws/src/balance_robot_description/`

Recovered visual assets now live in:

- `ros_ws/src/balance_robot_description/stl/body_side.stl`
- `ros_ws/src/balance_robot_description/stl/robot_neck.stl`
- `ros_ws/src/balance_robot_description/stl/head_rear.stl`
- `ros_ws/src/balance_robot_description/stl/head_top.stl`
- `ros_ws/src/balance_robot_description/stl/gemini335_case.stl`

The broader fabrication-oriented CAD and 3D-print archive is now organized in:

- `mechanical/`

That folder keeps editable CATPart/SLDPRT/STP material and print-oriented STL
exports separate from the short-name ROS visual mesh set.

The active LiDAR and depth Xacros now expose:

- `use_actual_stl_assembly:=true`

That flag swaps only the `base_link` visuals. Collision and inertia still stay
simple so the historical controller and navigation behavior do not change just
because the model looks closer to the real robot.

## Why This Matters

These assets are the clearest geometry baseline for future simulation cleanup
because they were exported from the actual robot build direction rather than
being only a generic box approximation.

This means future simulation edits can reference:

- the multi-part body silhouette
- the Gemini 335 case placement
- the archived visual assembly origin used in the original workspace

## Archived Frame Notes Worth Reviewing Later

The archived depth-model Xacro used these visual and frame values:

- STL assembly origin: `-0.110383 -0.202 0.064314`
- IMU joint origin: `0 0 0.49`
- camera joint origin: `0.0515 0.0 0.400`

The current repository still keeps its later simplified collision model and its
current sensor-frame placements unless you explicitly change them. That is
intentional for now, because this cleanup was about organizing the repo and
recovering the real-robot geometry baseline without silently retuning the
simulation behavior.

## Recommended Next Step For Simulation Edits

When you start modifying the simulation code itself, review these files first:

1. `ros_ws/src/balance_robot_description/urdf/balance_robot_urdf.xacro`
2. `ros_ws/src/balance_robot_description/urdf/balance_robot_urdf_depth.xacro`
3. `ros_ws/src/balance_robot_description/stl/README.md`
4. `archive_sources/legacy_workspace_archive/exported_balance_robot_stl_changes_20260507/urdf/balence_robot_urdf_depth.xacro`

That gives you the current GitHub baseline, the recovered real-robot visuals,
and the archived frame data in one place.

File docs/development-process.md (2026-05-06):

# Development Process

English | [한국어](ko/development-process.md)

## Purpose

This page organizes the recovered build-process material into a readable story instead of dumping raw presentation decks, private chat logs, or large source files into the repository.

The goal is to show how the robot moved from concept, CAD assembly, wiring, bench tests, tethered driving practice, and simulation into the final project results.

## Visual Build Story

### 1. Concept And Mechanical Assembly

The recovered CATIA material shows the intended physical form: a compact two-wheeled balancing robot with an upper sensor head and an internal electronics bay.

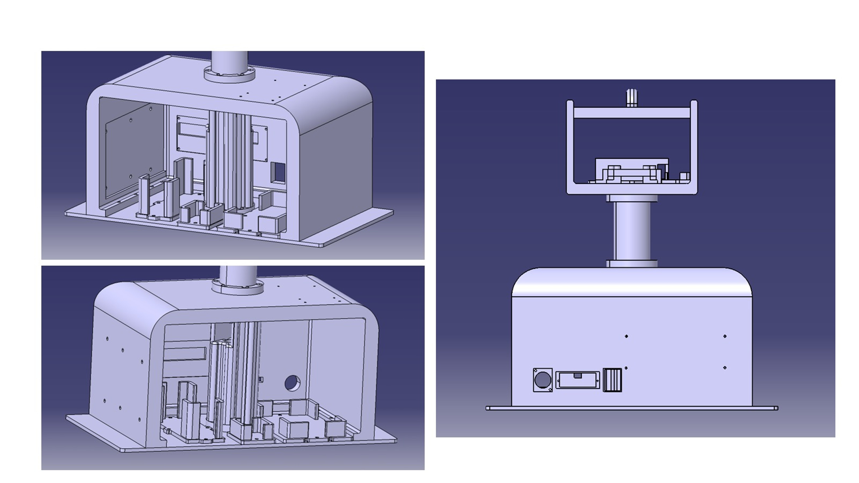
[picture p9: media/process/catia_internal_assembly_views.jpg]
CATIA internal assembly views


The CATIA assembly views make the hardware story easier to inspect than text alone. They show the body volume, internal packaging direction, upper mast, and rear/front layout before the physical wiring was finalized.

### 2. Head, Body, And Packaging Iteration

| Head design | Body design |
| --- | --- |
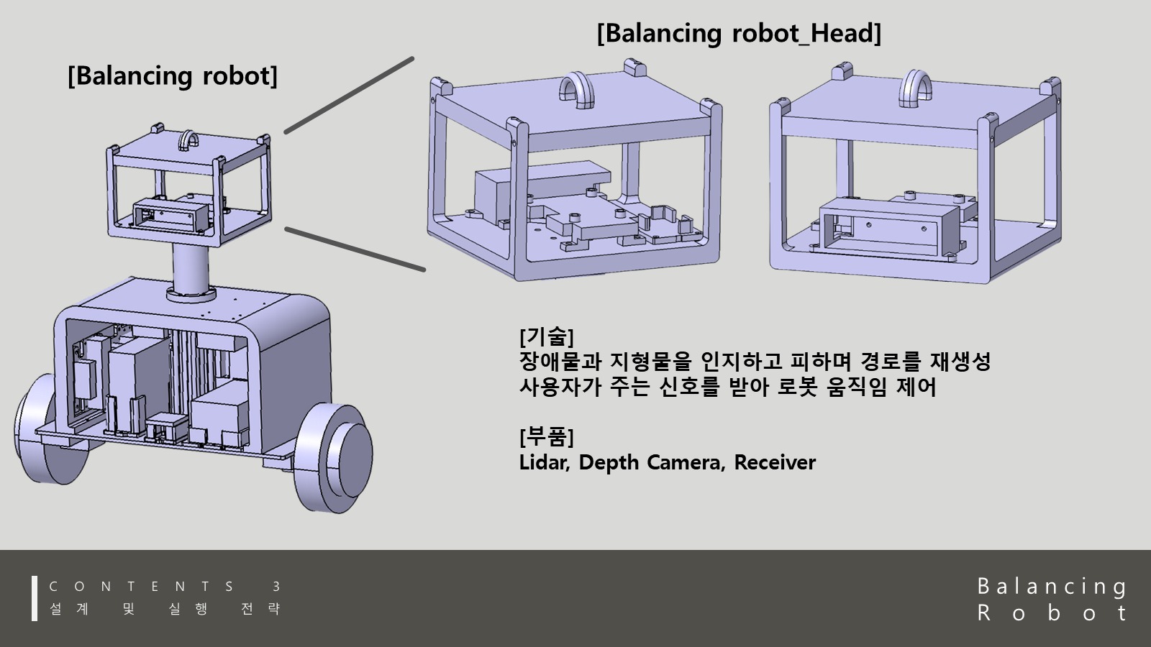
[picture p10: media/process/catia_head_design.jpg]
CATIA head design
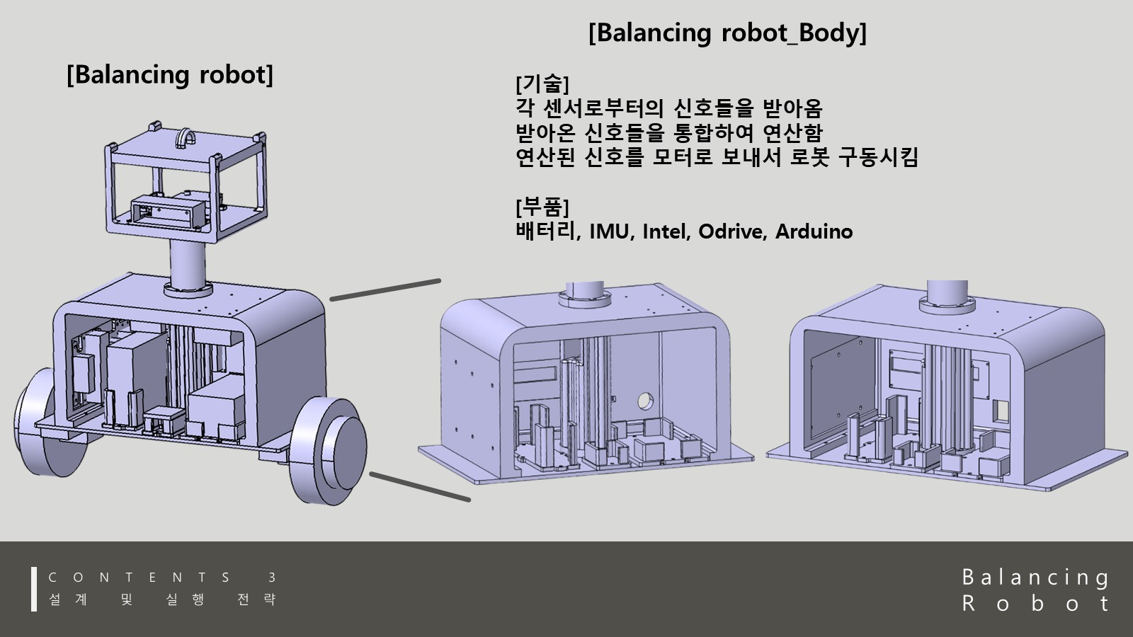
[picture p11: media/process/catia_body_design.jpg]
CATIA body design
|  |  |

These slides show that the robot was not only a software demo. The physical chassis, head enclosure, sensor placement, battery/compute space, and service opening were considered as part of the build.

### 3. Wiring And Control Architecture

Wiring Diagram

The Wiring Diagram connects the FrSky Taranis Q X7 / X8R radio path, Arduino Mega 2560, BNO055 IMU, ODrive 3.6, battery, voltage converters, onboard PC, Orbbec Gemini 330, auxiliary Arduino, and relay module. It is the repository's current public system-level summary of the robot wiring and control architecture.

### 4. Wheel And Motor Bench Testing

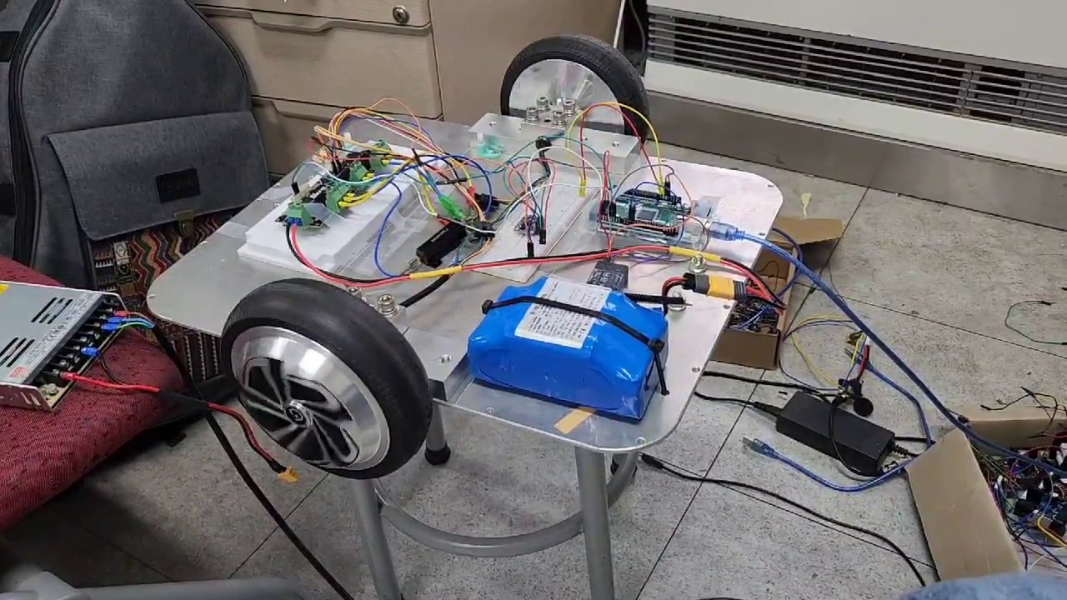
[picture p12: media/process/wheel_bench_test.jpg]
Wheel bench test


Before the completed robot demos, the wheel/motor/control electronics were tested on an open bench. This stage was important for checking ODrive bring-up, hall-sensor feedback, power wiring, and controller communication before balancing the full body.

### 5. Tethered Driving Practice

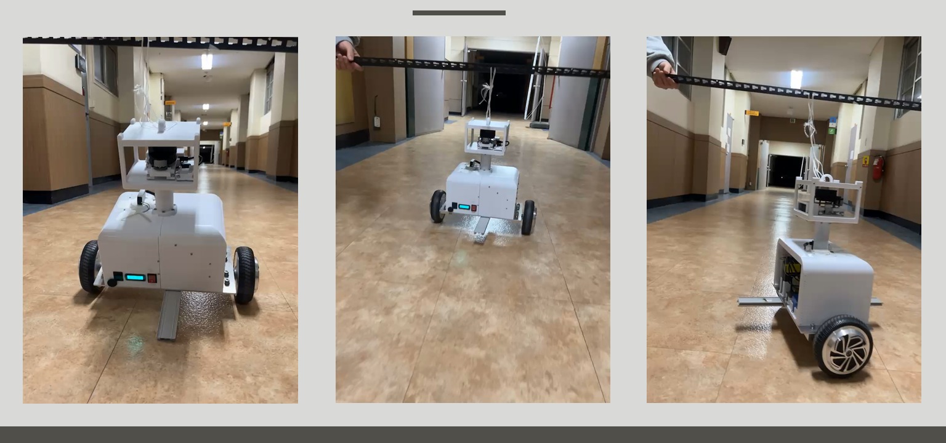
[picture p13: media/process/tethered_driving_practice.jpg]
Tethered driving practice


The tethered driving photos show the practical safety step between bench testing and free driving. The robot was practiced with an overhead support line while balance and drive parameters were adjusted.

### 6. Simulation And Navigation

Simulation depth-navigation views

The updated simulation capture shows the parallel ROS/Gazebo track with the depth-camera robot model, RViz map/navigation state, and Gazebo environment in one frame. The companion [depth-navigation WebM clip](../media/process/simulation_depth_navigation_demo.webm) records the workflow in motion. This is why the repository treats simulation navigation as a finished software-side result, while physical autonomous navigation stays in the partial category.

### 7. Sim2Real Bridge

The sim-to-real connection was built around the same principle on both sides: high-level commands are motion intent, not direct motor authority. In Gazebo this appears as `move_base -> /before_vel -> balance_robot_control -> /cmd_vel`; on the real robot it appears as RC or ROS-side intent entering the Arduino balance and safety loop before ODrive current commands are sent.

See [Sim2Real Bridge](sim2real.md) for the transfer points, real-world tuning gaps, and the boundary between completed simulation navigation and unfinished physical autonomous navigation.

## Build Timeline

| Phase | Focus | What that stage meant | Outcome |
| --- | --- | --- | --- |
| Concept definition | Two-wheeled guide robot with mobility, maneuverability, and efficient space use | Final presentation material framed the robot as a compact mobile guidance platform | Project goal narrowed to a balancing robot plus ROS navigation exploration |
| Subsystem planning | ODrive 3.6, Arduino Mega 2560, BNO055 IMU, FrSky Taranis Q X7 + X8R, Orbbec Gemini 330, and power conversion | Research notes and weekly reports separated hardware control from ROS navigation work | Main workstreams became physical balance control and ROS/Gazebo simulation |
| ODrive and motor bring-up | Ubuntu setup, ODrive tooling, voltage checks, firmware setup, motor and hall-sensor connection | Weekly report material records staged motor-controller bring-up before full robot integration | Motor control path was validated before balancing experiments |
| Control integration | Arduino Mega 2560, BNO055 IMU, FrSky X8R receiver, and ODrive command path | Firmware and process notes show IMU feedback, RC input, and motor command integration | Physical balancing and RC driving became the strongest real-world result |
| Hardware assembly | Internal placement, wiring, battery pack, converter chain, relay/auxiliary area | Recovered wiring notes and the internal photo were turned into cleaner public diagrams and photos | The hardware section now uses the raw photo plus the Wiring Diagram |
| ROS simulation and navigation | Gazebo balancing robot, `/before_vel`, SLAM/navigation launch composition | ROS packages show simulation control, mapping and navigation experiments, and launch integration | Simulation navigation is treated as completed; physical autonomous navigation is not |
| Sim2Real framing | Same 3D-printed design direction, command-layer separation, and safety-aware control boundary | The simulation used the robot design and ROS command structure while the physical robot kept low-level balance authority on Arduino | The repo explains what transferred, what required real tuning, and what remains future work |
| Portfolio recovery | Demos, firmware, ROS packages, archived notes, and lighter media | Raw project material was summarized instead of copied wholesale | The repository now separates the main results from older experiments and research material |

## Functional Workstreams

| Workstream | What it covered | Main files or media |
| --- | --- | --- |
| ODrive / motor | Motor controller setup, hall-sensor feedback, motor synchronization, current control experiments | `firmware/physical_balance_controller`, `firmware/testers/motor_current_test`, `firmware/testers/odrive_receiver_test`, `archive/arduino_firmware`, hardware photos |
| FrSky radio path | X8R PWM input, Taranis Q X7 manual commands, and engage/throttle/steering interpretation | `physical_balance_controller.ino`, `receiver_pwm_test.ino`, `rc_to_ros_cmd_vel_bridge.ino`, receiver troubleshooting notes |
| IMU / balancing | BNO055 angle and gyro feedback, balance-loop tuning, safety-constrained parameter testing | `physical_balance_controller.ino`, hallway and obstacle-course demos |
| ROS / navigation | Gazebo balancing simulation, `/before_vel` command separation, SLAM/navigation launch files | `ros_ws/src/balance_robot_control`, `ros_ws/src/navigation`, `ros_ws/src/balance_robot_workflows` |
| Sim2Real bridge | Transfer between the ROS/Gazebo command workflow and the physical Arduino balance loop | `docs/sim2real.md`, `ros_ws/src/balance_robot_control`, `firmware/physical_balance_controller` |
| Hardware assembly | Chassis packaging, internal electronics bay, battery and DC-DC power chain | `media/hardware`, `media/diagrams/wiring_diagram.png` |
| Research and documentation | CAN, Orbbec Gemini 330, ORB-SLAM2, RTAB-Map, FrSky receiver noise, and ROS autorun investigation | This page, `docs/troubleshooting.md`, and `docs/results-and-limitations.md` |

## Research And Design Decisions

The recovered research notes helped shape the project, but they are not separate finished deliverables. The important public-facing decisions are summarized here so the repository stays compact.

| Topic | What it influenced | Final repo framing |
| --- | --- | --- |
| CAN protocol | Communication options for vehicle-style or industrial motor-control systems | Useful background only; the final implementation is Arduino + ODrive, not a completed CAN bus system |
| ODrive bring-up | Voltage checks, firmware setup, hall-sensor connection, controller modes, and current-control testing | Treated as real subsystem bring-up that supports the physical balancing result |
| Orbbec Gemini 330 | Sensor-head direction, depth-camera placement, and physical ROS integration experiments | Listed as deployed hardware, while physical autonomous depth navigation remains partial |
| ORB-SLAM2 and RTAB-Map | Visual/RGB-D SLAM tradeoff research for mapping and navigation workflows | Kept as research context and simulation/integration background, not overstated as a finished physical deployment |
| FrSky receiver interference | Wire length, grounding, shielding, twisted signal-ground routing, and filtering | Folded into the troubleshooting story because it directly affected real RC control reliability |
| ROS autorun | Boot-time launch patterns using scripts or services | Documented only as investigated; not presented as a production-ready robot startup system |

## Component Bring-Up Process

The recovered process material shows that each major part was brought up separately before being treated as part of the full robot. This is the most important engineering story behind the final demos: the robot became stable only after the team reduced each component to a testable role.

| Component | Bring-up goal | Trial-and-error process | Stabilized use in the project |
| --- | --- | --- | --- |
| ODrive 3.6 | Drive both wheel motors reliably before balancing | Set up Ubuntu/ODrive tooling, checked input voltage, connected motor phases and hall sensors, tested controller modes, then moved from simple spin tests toward current commands; the repository now keeps a focused motor-current test sketch for that bring-up path | Used as the current-control motor driver commanded by Arduino firmware |
| Wheel motors + hall sensors | Read wheel motion well enough for balancing and drive correction | Compared motor speed feedback, filtered abnormal readings, counted hall-state transitions, and tuned speed-related feedback so the two wheels could respond together | Used for wheel speed feedback and motor synchronization during physical balance control |
| BNO055 IMU | Provide body angle and gyro feedback for the balance loop | Verified sensor startup, handled calibration data, stored offsets in EEPROM, and used angle/gyro readings as the core balancing signal | Used as the main physical attitude sensor in `physical_balance_controller.ino` |
| FrSky X8R + Taranis Q X7 | Convert manual remote input into safe steering, throttle, and engage commands | Measured PWM pulse width with interrupts, filtered noisy channel values, added thresholds around neutral, and used engage persistence to avoid accidental motor activation | Used for manual driving while balancing and for RC-to-ROS bridge testing |
| Arduino Mega 2560 | Keep the low-level balance loop deterministic and independent from ROS | Integrated PWM input, IMU readings, ODrive serial communication, safety checks, and current-command output in one firmware loop | Became the main physical controller for the completed real robot behavior |
| Power chain | Feed motor power, onboard compute, and low-voltage auxiliaries from one robot package | Recovered wiring notes show a 36V main bus, a 36V to 19V conversion stage, and a 19V to 5V stage for lower-voltage electronics | Documented through the clean power/IO diagram and internal hardware photo |
| Orbbec Gemini 330 | Explore perception hardware for SLAM/navigation | Compared depth-camera capability and SLAM approaches before the physical autonomous navigation path was fully completed | Kept as deployed sensor-head hardware and research context, not as a finished physical navigation result |
| ROS/Gazebo stack | Test balancing/navigation ideas without risking hardware | Built simulation launch files, separated navigation command input through `/before_vel`, and tuned control behavior in Gazebo | Used as the main simulation and navigation track |

## Trial-And-Error Highlights

| Challenge | Iteration path | Lesson captured in the repository |
| --- | --- | --- |
| Real balancing was sensitive to small tuning changes | Started with subsystem checks, then combined IMU angle, gyro rate, wheel speed feedback, and ODrive current commands under safety limits | Physical balancing makes the most sense when you look at the final controller and demos, not just scattered raw notes |
| RC input could jump or drift around neutral | PWM values were filtered, neutral thresholds were added, and engage logic required persistence before motor activation | Manual control was treated as a signal-processing problem, not just a wiring task |
| Motor feedback could produce unstable behavior if trusted blindly | Encoder speed history and filtering were used to reduce the effect of abnormal readings | Feedback quality mattered as much as the controller equation |
| IMU calibration affected repeatability | BNO055 calibration offsets were saved and loaded, and calibration status was exposed through serial output | Sensor calibration became part of the operating process |
| Hardware packaging created interpretation risk | Internal photos showed the real layout, but exact labels could be misleading if drawn directly on the image | Public docs now use raw photos plus a clean diagram instead of uncertain photo annotations |
| SLAM/navigation ambition went further than the finished physical result | Visual/depth SLAM and RTAB-Map/ORB-SLAM2 were researched while simulation navigation matured | The repository separates completed simulation work from partial physical integration |

## Problems And Resolutions

| Problem | What was learned | Portfolio-safe result |
| --- | --- | --- |
| Balance tuning on the real robot was sensitive to hall-sensor and IMU feedback | Physical testing needed staged safety setup and iterative parameter adjustment | Real balancing is shown through the physical demo media and firmware |
| FrSky receiver signals were vulnerable to wiring length and noise concerns | Shorter wiring, better connections, shielding/twisted signal-ground routing, and filtering were identified as mitigations | Troubleshooting is documented as engineering process, not as a final wiring guarantee |
| Depth-camera and SLAM options had integration uncertainty | Orbbec Gemini 330, ORB-SLAM2, and RTAB-Map were compared before final physical navigation was complete | Simulation and integration experiments are documented separately from completed physical balancing |
| Raw project files mixed useful material with private or noisy material | Public docs summarize the technical process and omit chat logs and raw decks | GitHub stays cleaner and avoids publishing unnecessary personal material |

## Final Summary

- Real robot balancing and RC driving were completed and are backed by firmware plus demo media.
- ROS/Gazebo balancing, SLAM-related launch composition, and simulation navigation were completed as software-side work.
- The sim-to-real bridge is documented as transfer of design, command layering, and safety boundaries, not as finished physical autonomous navigation.
- Real-world ROS SLAM/navigation integration existed as experiments, but full autonomous navigation on the physical robot is not presented as finished.
- Raw process artifacts are treated as source material for these summaries, not as primary public deliverables.

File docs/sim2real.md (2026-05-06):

# Sim2Real Bridge

English | [한국어](ko/sim2real.md)

This page explains how I used simulation and the physical robot together. It is intentionally conservative: the project completed physical self-balancing and RC driving, and it completed ROS/Gazebo navigation workflows in simulation. Full autonomous ROS navigation on the physical balancing robot remains future work.

## Core Idea

The main sim-to-real idea was not to let high-level motion commands bypass the balancing layer.

```text
Simulation:
teleop or move_base
  -> /before_vel
  -> balance_robot_control
  -> /cmd_vel
  -> Gazebo robot

Physical robot:
RC or ROS-side intent
  -> Arduino balance and safety loop
  -> ODrive current commands
  -> wheel motors
```

In simulation, `/before_vel` is the motion-intent topic. The balancing controller turns that intent into the final `/cmd_vel`. On the real robot, the Arduino plays the same safety role at a lower level: throttle or steering intent can ask the robot to move, but the IMU feedback, tilt cutoff, current clamp, and wheel-speed correction still decide what reaches the motors.

## What Transferred From Simulation To Hardware

| Transfer point | Simulation side | Physical side |
| --- | --- | --- |
| Robot form factor | Gazebo model followed the same two-wheeled layout and 3D-printed design direction | The real robot used the printed chassis, upper sensor structure, and internal electronics packaging |
| Command layering | Navigation and teleop publish intent before balance control | RC and ROS bridge paths are treated as commands into a local Arduino balance loop |
| Balance-aware motion | Desired velocity is converted into a lean or correction request before final motion output | RC throttle becomes a speed target that shifts the balance point instead of directly commanding wheel speed |
| Sensor workflow | Gazebo provides `/imu`, `/odom`, scan/depth, map, and RViz feedback for workflow testing | BNO055, ODrive feedback, RC PWM, and camera integration traces represent the real sensing path |
| Safety boundary | Simulation controllers stop or limit output when pitch becomes unsafe | Firmware has tilt cutoff, engage persistence, current clamp, and inactive-state reset |

## What Stayed Simulation-Only

The ROS navigation stack reached a cleaner state in Gazebo than on the physical robot. In simulation, the repository preserves launch files for control, LiDAR navigation, depth navigation, SLAM, and PID tuning. On the real robot, the strongest completed result is still Arduino-controlled balancing and RC driving.

That split matters because a balancing robot is not a normal differential-drive base. A planner can output a velocity command, but the robot must still preserve body angle, current limits, and recovery behavior. The simulation proved the command architecture and workflow composition; the physical robot proved the low-level balancing and driving behavior.

## What Needed Real-World Tuning

| Area | Why simulation was not enough | Repository evidence |
| --- | --- | --- |
| IMU angle and gyro behavior | Real calibration, mounting offset, and noise affected the balance loop | [`physical_balance_controller.ino`](../firmware/physical_balance_controller/physical_balance_controller.ino), [`control_algorithm.md`](../firmware/physical_balance_controller/control_algorithm.md) |
| RC input reliability | Receiver PWM values drifted and needed filtering, deadband, and engage persistence | [`troubleshooting.md`](troubleshooting.md) |
| Motor and wheel feedback | Hall feedback, current response, and wheel behavior had real hardware limits | [`motor_current_test.ino`](../firmware/testers/motor_current_test/motor_current_test.ino), [`hardware.md`](hardware.md) |
| Fall safety | Physical testing needed current clamps and tilt cutoff to protect the robot | [`results-and-limitations.md`](results-and-limitations.md) |
| Depth-camera integration | Camera, TF, SLAM, and navigation traces existed, but full physical autonomy was not completed | [`real-world integration archive`](../archive/ros_experiments/real_world_integration/README.md) |

## Honest Result

The project demonstrates a practical sim-to-real bridge in two directions:

- from simulation to hardware: balance-aware command separation, navigation workflow structure, robot layout, and tuning ideas
- from hardware back to simulation: safety constraints, real controller limits, and the need to keep final actuator authority below the high-level planner

The completed physical result is balancing and RC driving. The completed ROS result is simulation-side control, SLAM/navigation workflow composition, and command-path adaptation. The unfinished bridge is full end-to-end autonomous navigation on the physical balancing robot.

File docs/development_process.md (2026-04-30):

# Development Process

## Purpose

This page organizes the recovered build-process material into a readable story instead of dumping raw presentation decks, private chat logs, or large source files into the repository.

The goal is to show how the robot moved from concept, CAD assembly, wiring, bench tests, tethered driving practice, and simulation into the final project results.

## Visual Build Story

### 1. Concept And Mechanical Assembly

The recovered CATIA material shows the intended physical form: a compact two-wheeled balancing robot with an upper sensor head and an internal electronics bay.

CATIA internal assembly views

The CATIA assembly views make the hardware story easier to inspect than text alone. They show the body volume, internal packaging direction, upper mast, and rear/front layout before the physical wiring was finalized.

### 2. Head, Body, And Packaging Iteration

| Head design | Body design |
| --- | --- |
| CATIA head design | CATIA body design |

These slides show that the robot was not only a software demo. The physical chassis, head enclosure, sensor placement, battery/compute space, and service opening were considered as part of the build.

### 3. Wiring And Control Architecture

Wiring Diagram

The Wiring Diagram connects the FrSky Taranis Q X7 / X8R radio path, Arduino Mega 2560, BNO055 IMU, ODrive 3.6, battery, voltage converters, onboard PC, Orbbec Gemini 330, auxiliary Arduino, and relay module. It is the repository's current public system-level summary of the robot wiring and control architecture.

### 4. Wheel And Motor Bench Testing

Wheel bench test

Before the completed robot demos, the wheel/motor/control electronics were tested on an open bench. This stage was important for checking ODrive bring-up, hall-sensor feedback, power wiring, and controller communication before balancing the full body.

### 5. Tethered Driving Practice

Tethered driving practice

The tethered driving photos show the practical safety step between bench testing and free driving. The robot was practiced with an overhead support line while balance and drive parameters were adjusted.

### 6. Simulation And Navigation

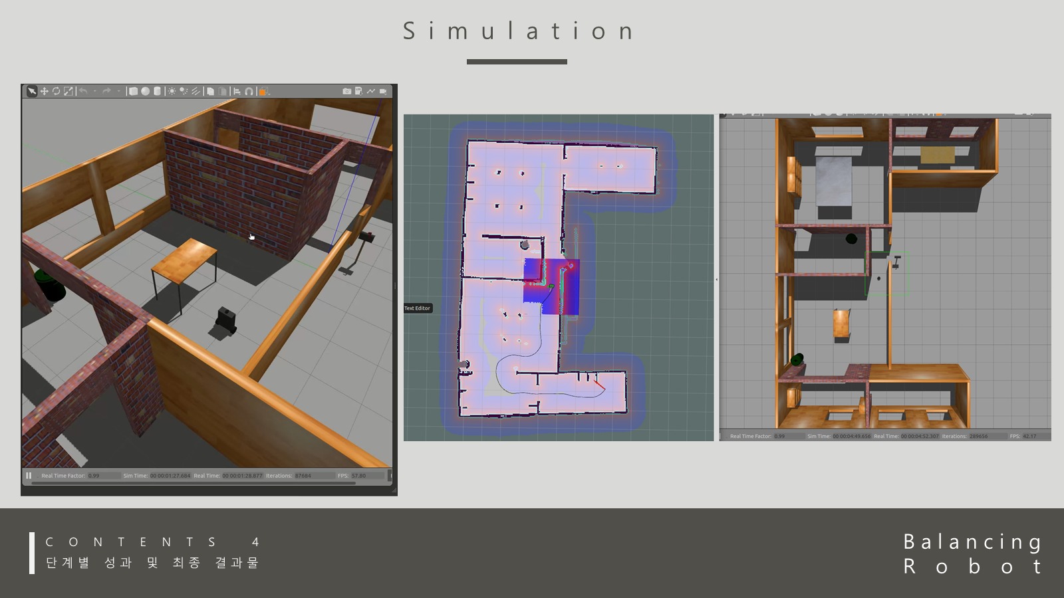
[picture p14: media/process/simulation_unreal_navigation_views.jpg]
Simulation navigation views


The simulation screenshots show the parallel ROS/Gazebo track: simulated robot placement, map and navigation views, and environment testing. This is why the repository treats simulation navigation as a finished software-side result, while physical autonomous navigation stays in the partial category.

## Build Timeline

| Phase | Focus | What that stage meant | Outcome |
| --- | --- | --- | --- |
| Concept definition | Two-wheeled guide robot with mobility, maneuverability, and efficient space use | Final presentation material framed the robot as a compact mobile guidance platform | Project goal narrowed to a balancing robot plus ROS navigation exploration |
| Subsystem planning | ODrive 3.6, Arduino Mega 2560, BNO055 IMU, FrSky Taranis Q X7 + X8R, Orbbec Gemini 330, and power conversion | Research notes and weekly reports separated hardware control from ROS navigation work | Main workstreams became physical balance control and ROS/Gazebo simulation |
| ODrive and motor bring-up | Ubuntu setup, ODrive tooling, voltage checks, firmware setup, motor and hall-sensor connection | Weekly report material records staged motor-controller bring-up before full robot integration | Motor control path was validated before balancing experiments |
| Control integration | Arduino Mega 2560, BNO055 IMU, FrSky X8R receiver, and ODrive command path | Firmware and process notes show IMU feedback, RC input, and motor command integration | Physical balancing and RC driving became the strongest real-world result |
| Hardware assembly | Internal placement, wiring, battery pack, converter chain, relay/auxiliary area | Recovered wiring notes and the internal photo were turned into cleaner public diagrams and photos | The hardware section now uses the raw photo plus the Wiring Diagram |
| ROS simulation and navigation | Gazebo balancing robot, `/before_vel`, SLAM/navigation launch composition | ROS packages show simulation control, mapping and navigation experiments, and launch integration | Simulation navigation is treated as completed; physical autonomous navigation is not |
| Portfolio recovery | Demos, firmware, ROS packages, archived notes, and lighter media | Raw project material was summarized instead of copied wholesale | The repository now separates the main results from older experiments and research material |

## Functional Workstreams

| Workstream | What it covered | Main files or media |
| --- | --- | --- |
| ODrive / motor | Motor controller setup, hall-sensor feedback, motor synchronization, current control experiments | `firmware/physical_balance_controller`, `firmware/testers/motor_current_test`, `firmware/testers/odrive_receiver_test`, `archive/arduino_firmware`, hardware photos |
| FrSky radio path | X8R PWM input, Taranis Q X7 manual commands, and engage/throttle/steering interpretation | `physical_balance_controller.ino`, `receiver_pwm_test.ino`, `rc_to_ros_cmd_vel_bridge.ino`, receiver troubleshooting notes |
| IMU / balancing | BNO055 angle and gyro feedback, balance-loop tuning, safety-constrained parameter testing | `physical_balance_controller.ino`, hallway and obstacle-course demos |
| ROS / navigation | Gazebo balancing simulation, `/before_vel` command separation, SLAM/navigation launch files | `ros_ws/src/balance_robot_control`, `ros_ws/src/navigation`, `ros_ws/src/balance_robot_workflows` |
| Hardware assembly | Chassis packaging, internal electronics bay, battery and DC-DC power chain | `media/hardware`, `media/diagrams/wiring_diagram.png` |
| Research and documentation | CAN, Orbbec Gemini 330, ORB-SLAM2, RTAB-Map, FrSky receiver noise, and ROS autorun investigation | `docs/research_and_design_decisions.md` |

## Component Bring-Up Process

The recovered process material shows that each major part was brought up separately before being treated as part of the full robot. This is the most important engineering story behind the final demos: the robot became stable only after the team reduced each component to a testable role.

| Component | Bring-up goal | Trial-and-error process | Stabilized use in the project |
| --- | --- | --- | --- |
| ODrive 3.6 | Drive both wheel motors reliably before balancing | Set up Ubuntu/ODrive tooling, checked input voltage, connected motor phases and hall sensors, tested controller modes, then moved from simple spin tests toward current commands; the repository now keeps a focused motor-current test sketch for that bring-up path | Used as the current-control motor driver commanded by Arduino firmware |
| Wheel motors + hall sensors | Read wheel motion well enough for balancing and drive correction | Compared motor speed feedback, filtered abnormal readings, counted hall-state transitions, and tuned speed-related feedback so the two wheels could respond together | Used for wheel speed feedback and motor synchronization during physical balance control |
| BNO055 IMU | Provide body angle and gyro feedback for the balance loop | Verified sensor startup, handled calibration data, stored offsets in EEPROM, and used angle/gyro readings as the core balancing signal | Used as the main physical attitude sensor in `physical_balance_controller.ino` |
| FrSky X8R + Taranis Q X7 | Convert manual remote input into safe steering, throttle, and engage commands | Measured PWM pulse width with interrupts, filtered noisy channel values, added thresholds around neutral, and used engage persistence to avoid accidental motor activation | Used for manual driving while balancing and for RC-to-ROS bridge testing |
| Arduino Mega 2560 | Keep the low-level balance loop deterministic and independent from ROS | Integrated PWM input, IMU readings, ODrive serial communication, safety checks, and current-command output in one firmware loop | Became the main physical controller for the completed real robot behavior |
| Power chain | Feed motor power, onboard compute, and low-voltage auxiliaries from one robot package | Recovered wiring notes show a 36V main bus, a 36V to 19V conversion stage, and a 19V to 5V stage for lower-voltage electronics | Documented through the clean power/IO diagram and internal hardware photo |
| Orbbec Gemini 330 | Explore perception hardware for SLAM/navigation | Compared depth-camera capability and SLAM approaches before the physical autonomous navigation path was fully completed | Kept as deployed sensor-head hardware and research context, not as a finished physical navigation result |
| ROS/Gazebo stack | Test balancing/navigation ideas without risking hardware | Built simulation launch files, separated navigation command input through `/before_vel`, and tuned control behavior in Gazebo | Used as the main simulation and navigation track |

## Trial-And-Error Highlights

| Challenge | Iteration path | Lesson captured in the repository |
| --- | --- | --- |
| Real balancing was sensitive to small tuning changes | Started with subsystem checks, then combined IMU angle, gyro rate, wheel speed feedback, and ODrive current commands under safety limits | Physical balancing makes the most sense when you look at the final controller and demos, not just scattered raw notes |
| RC input could jump or drift around neutral | PWM values were filtered, neutral thresholds were added, and engage logic required persistence before motor activation | Manual control was treated as a signal-processing problem, not just a wiring task |
| Motor feedback could produce unstable behavior if trusted blindly | Encoder speed history and filtering were used to reduce the effect of abnormal readings | Feedback quality mattered as much as the controller equation |
| IMU calibration affected repeatability | BNO055 calibration offsets were saved and loaded, and calibration status was exposed through serial output | Sensor calibration became part of the operating process |
| Hardware packaging created interpretation risk | Internal photos showed the real layout, but exact labels could be misleading if drawn directly on the image | Public docs now use raw photos plus a clean diagram instead of uncertain photo annotations |
| SLAM/navigation ambition went further than the finished physical result | Visual/depth SLAM and RTAB-Map/ORB-SLAM2 were researched while simulation navigation matured | The repository separates completed simulation work from partial physical integration |

## Problems And Resolutions

| Problem | What was learned | Portfolio-safe result |
| --- | --- | --- |
| Balance tuning on the real robot was sensitive to hall-sensor and IMU feedback | Physical testing needed staged safety setup and iterative parameter adjustment | Real balancing is shown through the physical demo media and firmware |
| FrSky receiver signals were vulnerable to wiring length and noise concerns | Shorter wiring, better connections, shielding/twisted signal-ground routing, and filtering were identified as mitigations | Troubleshooting is documented as engineering process, not as a final wiring guarantee |
| Depth-camera and SLAM options had integration uncertainty | Orbbec Gemini 330, ORB-SLAM2, and RTAB-Map were compared before final physical navigation was complete | Simulation and integration experiments are documented separately from completed physical balancing |
| Raw project files mixed useful material with private or noisy material | Public docs summarize the technical process and omit chat logs and raw decks | GitHub stays cleaner and avoids publishing unnecessary personal material |

## Final Summary

- Real robot balancing and RC driving were completed and are backed by firmware plus demo media.
- ROS/Gazebo balancing, SLAM-related launch composition, and simulation navigation were completed as software-side work.
- Real-world ROS SLAM/navigation integration existed as experiments, but full autonomous navigation on the physical robot is not presented as finished.
- Raw process artifacts are treated as source material for these summaries, not as primary public deliverables.

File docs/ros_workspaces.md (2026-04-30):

# ROS Workspaces: Simulation and Real-World Integration

The original project archive did not evolve as one clean ROS workspace. It split into multiple workspaces over time as balancing control, Gazebo simulation, SLAM, navigation, camera integration, and physical-robot experiments were explored in parallel.

This repository keeps that history in a cleaner form:

- `ros_ws/` is the curated simulation-focused ROS workspace.
- `archive/ros_experiments/real_world_integration/` stores representative real-robot ROS integration traces.
- `archive/arduino_firmware/` and `firmware/testers/` preserve the Arduino-to-ROS side of the bridge work.

## Original Workspace Meanings

### `simul_br_ws`

`simul_br_ws` was the main simulation workspace for the balancing robot.

Its main job was:

1. spawn the balancing robot in Gazebo,
2. run a custom balancing controller,
3. optionally feed that controller from teleop or `move_base`,
4. test SLAM and navigation on top of the balancing layer.

The most important design decision in this workspace was the command pipeline:

`move_base -> /before_vel -> balance controller -> /cmd_vel`

That means navigation did not drive the robot base directly. Navigation only produced a desired motion command, and the custom balance controller converted that request into a motion that tried to keep the robot upright.

#### `simul_br_ws` -> current repository mapping

| Original role | Current location | What it does |
| --- | --- | --- |
| balancing control nodes | [ros_ws/src/balance_robot_control](../ros_ws/src/balance_robot_control/README.md) | file-by-file balancing controller logic, tuning helpers, auto-tuning experiments |
| high-level launch composition | [ros_ws/src/balance_robot_workflows](../ros_ws/src/balance_robot_workflows/README.md) | bundles controller, Gazebo, SLAM, and navigation launch flows |
| navigation stack | [ros_ws/src/navigation](../ros_ws/src/navigation/README.md) | `map_server`, `amcl`, `move_base`, map assets, DWA config |
| Gazebo robot launch presets | `ros_ws/src/balance_robot_gazebo` | starts house/depth/lidar simulation worlds and controller entrypoints |
| URDF/Xacro robot model | `ros_ws/src/balance_robot_description` | robot body, wheels, IMU, lidar/depth model definitions |
| earlier controller variants | [archive/ros_experiments/pid_experiments](../archive/ros_experiments/pid_experiments/README.md) | older control ideas that came before the cleaned `/before_vel` structure |

### `real_br_ws_intel`

`real_br_ws_intel` was the later physical-robot ROS integration workspace.

Its goal was not low-level balancing on ROS. Instead, it attempted to:

1. bring depth-camera data into ROS from an Intel-class onboard PC,
2. subscribe to robot state information coming from the physical robot, especially `/imu` and `/odom`,
3. publish TF and robot model information for RViz and RTAB-Map,
4. try SLAM and navigation on the physical platform.

The important limitation is that this workspace represents integration attempts, not a fully verified autonomous physical navigation result.

- ROS-Arduino communication was achieved.
- camera + TF + visualization + SLAM launch composition was attempted.
- end-to-end physical SLAM/navigation success is not claimed here.

#### `real_br_ws_intel` -> current repository mapping

| Original package or role | Current location | What it means |
| --- | --- | --- |
| historical workflow-launch layer | [archive/ros_experiments/real_world_integration/robot_slam.launch](../archive/ros_experiments/real_world_integration/robot_slam.launch), [archive/ros_experiments/real_world_integration/robot_navigation.launch](../archive/ros_experiments/real_world_integration/robot_navigation.launch) | Orbbec camera bring-up, RTAB-Map, depth-to-scan conversion, partial navigation front-end |
| `robot_rviz` TF and RViz helpers | [archive/ros_experiments/real_world_integration/robot_description_rviz.launch](../archive/ros_experiments/real_world_integration/robot_description_rviz.launch), [imu_tf.py](../archive/ros_experiments/real_world_integration/imu_tf.py), [odom_tf.py](../archive/ros_experiments/real_world_integration/odom_tf.py), [visual_odom_tf.py](../archive/ros_experiments/real_world_integration/visual_odom_tf.py) | converts `/imu` and `/odom` into TF frames usable by RViz and SLAM |
| launch control helper | [archive/ros_experiments/real_world_integration/launch_service.py](../archive/ros_experiments/real_world_integration/launch_service.py) | start/stop services for SLAM and navigation launch files |
| camera driver dependency | third-party dependency, not vendored in cleaned repo | `OrbbecSDK_ROS1` publishes `/camera/depth/image_raw`, `/camera/color/image_raw`, camera info, and camera control services |
| physical robot `/imu` and `/odom` publishers | [archive/arduino_firmware/legacy_balance_controller.ino](../archive/arduino_firmware/legacy_balance_controller.ino), [experimental_balance_controller_imu_ros.ino](../archive/arduino_firmware/experimental_balance_controller_imu_ros.ino) | archived `rosserial` firmware traces that published robot-state topics into ROS |
| RC-to-ROS bridge experiment | [firmware/testers/rc_to_ros_cmd_vel_bridge.ino](../firmware/testers/rc_to_ros_cmd_vel_bridge.ino) | Arduino bridge that published ROS motion commands from RC input |

## Important Interpretation Notes

### `real_br_ws_intel` was not a full navigation workspace yet

One of the easiest ways to misunderstand the original archive is to trust filenames too literally.

For example, the recovered `robot_navigation.launch` from the real-world integration workspace does **not** launch a full `move_base` + `amcl` navigation stack. It mainly starts the Orbbec camera and `depthimage_to_laserscan`, which makes it more of a sensor front-end experiment than a complete navigation pipeline.

### ROS was consuming physical robot state, not generating it

The real-world launch files subscribe to `/imu` and `/odom`, but they do not generate those topics themselves.

That information was expected to come from the physical robot side, via Arduino and ROS bridging experiments. In other words, the ROS integration workspace was the consumer of robot state, not the low-level source of balancing state estimation.

### `real_br_ws_intel` still carried simulation-era baggage

The original workspace also contained `robot_gazebo`, robot-description world assets, and other simulation artifacts. That is useful historical evidence, but it also shows that the workspace was a mixed integration sandbox rather than a tightly scoped final product.

## Recommended Reading Order

1. [ros_ws/src/balance_robot_control/README.md](../ros_ws/src/balance_robot_control/README.md)
2. [ros_ws/src/balance_robot_workflows/README.md](../ros_ws/src/balance_robot_workflows/README.md)
3. [ros_ws/src/navigation/README.md](../ros_ws/src/navigation/README.md)
4. [archive/ros_experiments/real_world_integration/README.md](../archive/ros_experiments/real_world_integration/README.md)
5. [docs/results_and_limitations.md](results_and_limitations.md)

That sequence explains what the simulation workspace actually accomplished, what the cleaned package entrypoints are, and where the physical-robot ROS integration stopped.

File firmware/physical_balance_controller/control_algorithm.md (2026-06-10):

# Physical Balance Control Algorithm

This document explains the structure of the real robot controller implemented in
[`physical_balance_controller.ino`](physical_balance_controller.ino).

The important idea is that the Arduino is not just passing commands through. It is the real-time safety and balance controller. RC input asks for motion, the IMU tells the robot how far it is leaning, ODrive feedback estimates wheel speed, and the final output is a current command to each wheel motor.

<p align="center">
  Physical balance control loop
</p>

## Control Responsibility

| Part | Role in the controller |
| --- | --- |
| FrSky X8R receiver | Provides `throttle`, `steering`, and `engage` PWM signals from the handheld controller |
| BNO055 IMU | Provides body tilt angle, tilt rate, and yaw rate |
| Arduino Mega 2560 | Runs filtering, safety checks, balance control, speed correction, steering correction, and motor-current mixing |
| ODrive 3.6 | Receives current commands and drives the two hub motors |
| Hub motor hall/encoder feedback | Provides wheel-speed information used for speed correction |

## Main Runtime Loop

The Arduino loop is split into small scheduled jobs using `Metro`.

| Job | Code path | Purpose |
| --- | --- | --- |
| Controller update | `BalanceController()` then `ApplyMotorCommands()` | Reads sensors, calculates correction terms, sends motor current |
| Activation update | `EngageMotors()` | Uses the filtered engage switch and tilt safety flag to enter or leave ODrive closed-loop mode |
| Optional serial printing | `PrintRcSignals()` | Debug output for raw and filtered RC signal inspection |
| Serial command parsing | `cmd.parse_command()` | Allows gain tuning while the controller is running |

## Input Filtering

The RC receiver values are noisy enough that the controller filters them before use.

```text
filtered_pwm = alpha * raw_pwm + (1 - alpha) * previous_filtered_pwm
```

The sketch uses different filter strengths for different signals:

| Signal | Filter value | Why it matters |
| --- | --- | --- |
| `throttle` | `kAlpha_1 = 0.4` | Smooths forward/backward command without making driving feel too delayed |
| `steering` | `kAlpha_1 = 0.4` | Smooths left/right command |
| `engage` | `kAlpha_2 = 0.02` | Makes motor activation less sensitive to short PWM spikes |

After filtering, throttle and steering use a neutral deadband around the receiver center value. This prevents small stick noise from becoming unwanted motion.

## Safety Layer

The controller has two main safety gates before motors are allowed to stay active.

```text
motors_active = engage_request && !tilt_limit_exceeded
```

| Safety behavior | Implementation detail |
| --- | --- |
| Engage persistence | The engage PWM must remain above the threshold long enough to pass the persistence counter |
| Tilt cutoff | If body tilt exceeds `kTiltDisengageThresholdDegrees = 30`, the controller marks `tilt_limit_exceeded` and exits the balance calculation |
| Integral reset | Balance integral error is reset when motors are inactive or tilt safety is exceeded |
| Current limit | Final current commands are constrained to `-8A` to `+8A` before being sent to ODrive |

## Balance Term

The core balancing term uses the body angle from the BNO055 and the angular velocity from the gyroscope.

```text
theta     = body tilt angle + imu_angle_offset
theta_dot = body tilt angular velocity

balance_controller =
  (K_theta / 100)     * theta
- (K_theta_dot / 100) * theta_dot
+ (Ki / 100)          * integral_error
```

In the code this is named `balance_controller`. It is the term that tries to keep the robot body upright.

## What Kind Of Controller This Actually Is

The deployed robot controller is best understood as a layered controller rather than one isolated textbook regulator:

- a `body-angle and angular-rate balance term` on `theta` and `theta_dot`
- an `integral correction` to reduce steady-state lean bias
- a `PID-like speed loop` that turns throttle request into a forward or backward balance bias
- a `steering and yaw-damping loop` that creates left-right current difference
- a `safety supervisor` that can refuse activation or drop the motors to idle

That distinction matters. A balancing robot is an unstable plant. The job is not only to compute one torque value, but also to decide when the robot is safe enough to apply torque at all, how aggressively it should accelerate, and how to keep steering commands from corrupting the upright loop.

## Speed Correction

The controller converts ODrive wheel-speed feedback into estimated linear velocity:

```text
v_left_or_right = motor_direction * wheel_speed * 2 * PI * wheel_radius
```

Throttle input becomes a target speed:

```text
target_speed = throttle_input * maxspeed
```

Then a PID-like speed correction is calculated:

```text
speed_error = target_speed - average_wheel_speed

speed_control =
  kpspeed * speed_error
+ kispeed * integral_speed_error
- kdspeed * derivative_speed_error
```

This term lets RC throttle ask the robot to move forward or backward while the balance term still keeps it upright.

## Steering Correction

Steering combines the filtered receiver steering signal with the IMU yaw rate:

```text
steering_controller = kpSteer * steering + kdSteer * yaw_rate
```

The result is mixed with opposite signs on the left and right motor commands, so the robot can turn while balancing.

## Motor Mixing

The final current request is built from three terms:

```text
motor_0 = balance_controller - speed_control - steering_controller
motor_1 = balance_controller - speed_control + steering_controller
```

Then a small optional `tanh()` compensation term can be added to reduce low-speed bias or friction effects:

```text
motor_0 += adjustment_value * tanh(scaling_factor * wheel_speed_0)
motor_1 -= adjustment_value * tanh(scaling_factor * wheel_speed_1)
```

Finally, both commands are clamped and sent to ODrive:

```text
current_command = constrain(motor_command, -kMaxAbsCurrent, kMaxAbsCurrent)
ODrive.SetCurrent(axis, motor_direction * current_command)
```

## Why This Structure Was Necessary

A normal differential-drive robot can often treat `throttle -> wheel velocity` as the main problem. This robot could not. Forward motion had to be created by intentionally shifting the balance point without letting the body tip too far, and steering had to be introduced without destroying the stabilization term already fighting gravity.

That is why the controller is layered in this order:

1. Estimate whether the body is still inside a safe tilt window.
2. Compute the stabilizing balance torque from `theta` and `theta_dot`.
3. Add a speed correction that biases the robot to roll forward or backward.
4. Add a steering correction with opposite sign on the two wheels.
5. Clamp the final current and send it to ODrive only if the safety state allows it.

This structure is what turns the robot from a bench motor experiment into a driveable self-balancing system.

## How The Algorithm Solved Real Problems

The control structure is tied directly to the troubleshooting history:

- `RC noise and PWM spikes`: raw receiver PWM is filtered before it affects throttle, steering, or engage state.
- `Accidental motor activation`: the engage switch is not trusted instantly; it must pass a persistence filter first.
- `Fall risk during tuning`: the tilt cutoff can force the control path into a safe inactive state.
- `Aggressive current bursts`: current commands are clamped before being sent to ODrive.
- `Forward motion while balancing`: throttle does not bypass the balance term; it becomes a target speed that modifies the equilibrium indirectly.
- `Turning instability`: steering is mixed as a differential term so the robot can rotate without throwing away the common balance effort.

In other words, the algorithm is not only a control law. It is also the distilled record of what had to be added so the real hardware would stop behaving like a collection of fragile subsystems.

## Tuning Symptoms And Tradeoffs

| If this part is wrong | Likely behavior | Why it happens |
| --- | --- | --- |
| `K_theta` too low | slow falling or weak recovery | body angle error is not corrected strongly enough |
| `K_theta` too high | sharp oscillation or chatter | angle error is over-amplified into current command |
| `K_theta_dot` too low | overshoot after a lean | body angular velocity is not damped enough |
| `K_theta_dot` too high | stiff, noisy, or hesitant response | gyro-rate term suppresses motion too aggressively |
| `Ki` too high | creeping or slow oscillation | accumulated bias correction starts to dominate |
| `kpspeed`, `kispeed`, `kdspeed` poorly tuned | surging, hunting, or poor speed tracking | the robot is moving the balance point incorrectly |
| `kpSteer` or `kdSteer` too high | unstable turning or wheel asymmetry | steering correction overwhelms the common balance term |
| RC deadband too small | wheels react to stick noise near neutral | small PWM drift is treated like user intent |
| current clamp too high during early tuning | hard falls or violent recovery | the actuator can inject too much energy before the operator reacts |

## Tuning Interface

The sketch exposes a small serial tuning interface through `Command_processor`.

| Command | Parameter changed | Meaning |
| --- | --- | --- |
| `q` | `K_theta` | Body-angle balance gain |
| `w` | `Ki` | Balance integral gain |
| `e` | `K_theta_dot` | Body angular-velocity gain |
| `r` | `imu_angle_offset` | Mechanical/sensor angle offset |
| `t` | `adjustment_value` | Extra low-speed compensation amount |
| `y` | `scaling_factor` | Shape of the `tanh()` compensation |
| `a` | `kpspeed` | Speed-loop proportional gain |
| `s` | `kispeed` | Speed-loop integral gain |
| `d` | `kdspeed` | Speed-loop derivative gain |

## Why This Structure Matters

A balancing robot cannot treat throttle like a normal wheeled robot. The controller must first keep the body upright, then bias that balance point to create forward/backward motion, and finally add steering as a difference between the two wheels.

That is why the firmware is structured as:

```text
RC request + IMU state + wheel feedback
  -> safety checks
  -> balance correction
  -> speed correction
  -> steering correction
  -> left/right current commands
  -> ODrive
```

This is also why the real robot keeps the low-level control loop on Arduino instead of depending on ROS for balance timing.

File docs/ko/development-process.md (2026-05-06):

# 개발 과정

[English](../development-process.md) | 한국어

## 목적

이 문서는 복구된 제작 과정 자료를 그대로 쌓아두는 대신, 읽기 쉬운 개발 이야기로 정리한 문서입니다. 원본 발표 자료, 개인 대화 기록, 큰 source file을 저장소에 그대로 넣기보다, 공개 가능한 핵심 흐름만 정리했습니다.

목표는 로봇이 concept, CAD assembly, wiring, bench test, tethered driving practice, simulation을 거쳐 최종 결과까지 어떻게 이어졌는지 보여주는 것입니다.

## Visual Build Story

### 1. Concept And Mechanical Assembly

복구된 CATIA 자료는 상단 sensor head와 내부 electronics bay를 가진 compact two-wheeled balancing robot이라는 의도된 물리 구조를 보여줍니다.

CATIA internal assembly views

CATIA assembly view는 하드웨어 이야기를 텍스트보다 쉽게 확인하게 해줍니다. 실제 wiring이 확정되기 전의 body volume, internal packaging direction, upper mast, front/rear layout을 보여줍니다.

### 2. Head, Body, And Packaging Iteration

| Head design | Body design |
| --- | --- |
| CATIA head design | CATIA body design |

이 자료들은 이 프로젝트가 단순한 software demo가 아니었음을 보여줍니다. Physical chassis, head enclosure, sensor placement, battery/compute space, service opening이 제작 과정에서 함께 고려되었습니다.

### 3. Wiring And Control Architecture

Wiring Diagram

Wiring Diagram은 FrSky Taranis Q X7 / X8R radio path, Arduino Mega 2560, BNO055 IMU, ODrive 3.6, battery, voltage converters, onboard PC, Orbbec Gemini 330, auxiliary Arduino, relay module을 연결해서 보여줍니다. 현재 저장소에서 공개용 system-level wiring/control summary 역할을 합니다.

### 4. Wheel And Motor Bench Testing

Wheel bench test

완성된 로봇 데모 전에 wheel, motor, control electronics를 open bench에서 테스트했습니다. 이 단계는 full body balancing 전에 ODrive bring-up, hall-sensor feedback, power wiring, controller communication을 확인하는 데 중요했습니다.

### 5. Tethered Driving Practice

Tethered driving practice

Tethered driving photo는 bench testing과 free driving 사이의 practical safety step을 보여줍니다. Balance와 drive parameter를 조정하는 동안 로봇을 overhead support line으로 지지한 상태에서 연습했습니다.

### 6. Simulation And Navigation

Simulation depth-navigation views

업데이트된 simulation capture는 depth-camera robot model, RViz map/navigation state, Gazebo environment를 한 화면에서 보여줍니다. 함께 넣은 [depth-navigation WebM clip](../../media/process/simulation_depth_navigation_demo.webm)은 workflow가 실제로 움직이는 장면을 기록합니다. 그래서 이 저장소는 simulation navigation을 완료된 software-side result로 다루고, physical autonomous navigation은 partial category로 분리합니다.

### 7. Sim2Real Bridge

Sim-to-real 연결은 양쪽 모두 같은 원칙을 따릅니다. High-level command는 motion intent이지 direct motor authority가 아닙니다. Gazebo에서는 `move_base -> /before_vel -> balance_robot_control -> /cmd_vel` 구조로 나타나고, 실제 로봇에서는 RC 또는 ROS-side intent가 Arduino balance/safety loop를 거친 뒤 ODrive current command로 나갑니다.

Transfer point, 실제 tuning gap, completed simulation navigation과 unfinished physical autonomous navigation의 경계는 [Sim2Real Bridge](sim2real.md)에 정리했습니다.

## Build Timeline
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

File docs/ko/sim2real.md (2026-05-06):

# Sim2Real Bridge

[English](../sim2real.md) | 한국어

이 문서는 simulation과 실제 로봇을 어떻게 연결해서 사용했는지 설명합니다. 일부러 보수적으로 정리했습니다. 이 프로젝트는 실제 로봇의 self-balancing 및 RC driving을 완료했고, ROS/Gazebo navigation workflow는 simulation에서 완료했습니다. 실제 balancing robot에서 full autonomous ROS navigation은 future work로 남겨 둡니다.

## Core Idea

가장 중요한 sim-to-real 아이디어는 high-level motion command가 balancing layer를 우회하지 않게 만드는 것이었습니다.

```text
Simulation:
teleop or move_base
  -> /before_vel
  -> balance_robot_control
  -> /cmd_vel
  -> Gazebo robot

Physical robot:
RC or ROS-side intent
  -> Arduino balance and safety loop
  -> ODrive current commands
  -> wheel motors
```

Simulation에서는 `/before_vel`이 motion intent topic입니다. Balancing controller가 그 intent를 받아 final `/cmd_vel`로 바꿉니다. 실제 로봇에서는 Arduino가 더 낮은 레벨에서 같은 safety role을 맡습니다. Throttle, steering, ROS-side intent가 로봇에 움직임을 요청할 수는 있지만, IMU feedback, tilt cutoff, current clamp, wheel-speed correction을 거친 뒤에야 motor command가 결정됩니다.

## What Transferred From Simulation To Hardware

| Transfer point | Simulation side | Physical side |
| --- | --- | --- |
| Robot form factor | Gazebo model이 같은 two-wheeled layout과 3D-printed design direction을 따름 | 실제 로봇은 printed chassis, upper sensor structure, internal electronics packaging을 사용 |
| Command layering | Navigation과 teleop이 balance control 전에 intent를 publish | RC와 ROS bridge path를 local Arduino balance loop로 들어가는 command로 처리 |
| Balance-aware motion | Desired velocity를 final motion output 전에 lean 또는 correction request로 변환 | RC throttle을 wheel speed direct command가 아니라 balance point를 이동시키는 speed target으로 사용 |
| Sensor workflow | Gazebo가 `/imu`, `/odom`, scan/depth, map, RViz feedback으로 workflow test 제공 | BNO055, ODrive feedback, RC PWM, camera integration trace가 실제 sensing path를 구성 |
| Safety boundary | Simulation controller가 pitch가 unsafe해지면 output을 stop 또는 limit | Firmware에 tilt cutoff, engage persistence, current clamp, inactive-state reset 존재 |
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

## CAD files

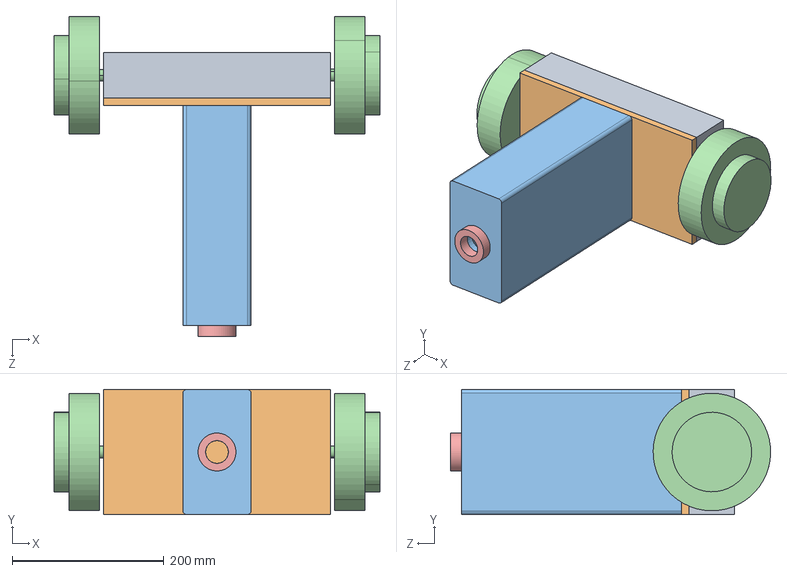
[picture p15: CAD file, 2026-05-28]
mechanical/new_balancerobot_concept/assemble/balence_robot.SLDASM
430.0 x 165.0 x 422.5 mm
밑면아래
밑면위
몸통
balancing robot_wheel x 2
목

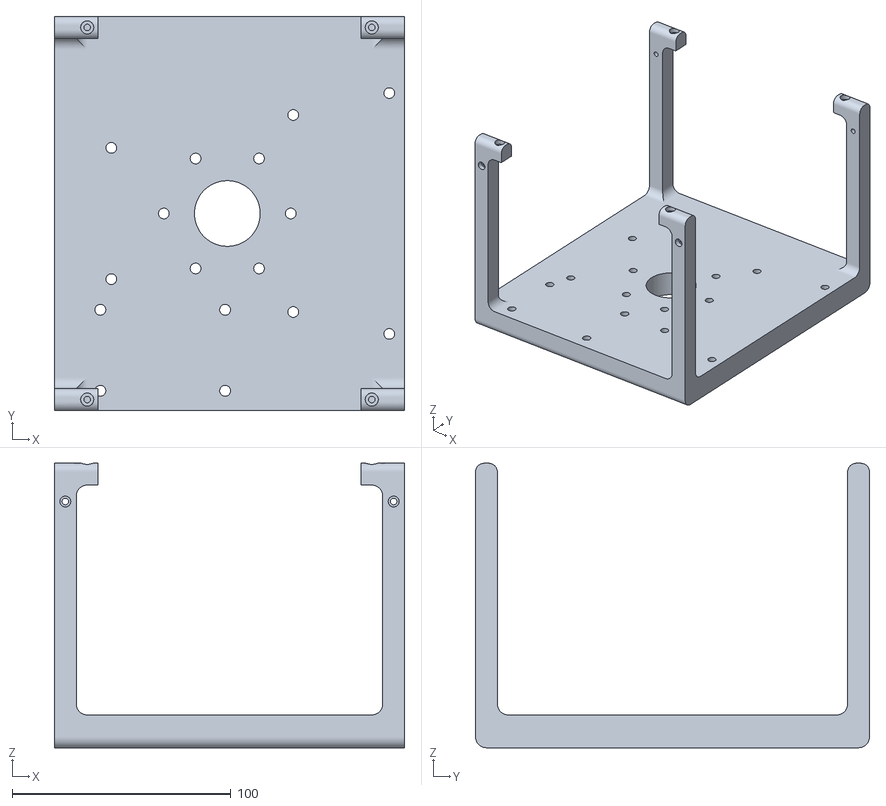
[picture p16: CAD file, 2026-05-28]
mechanical/head_sensor_mount/Head_ver_re1.stl
160.0 x 180.0 x 130.0

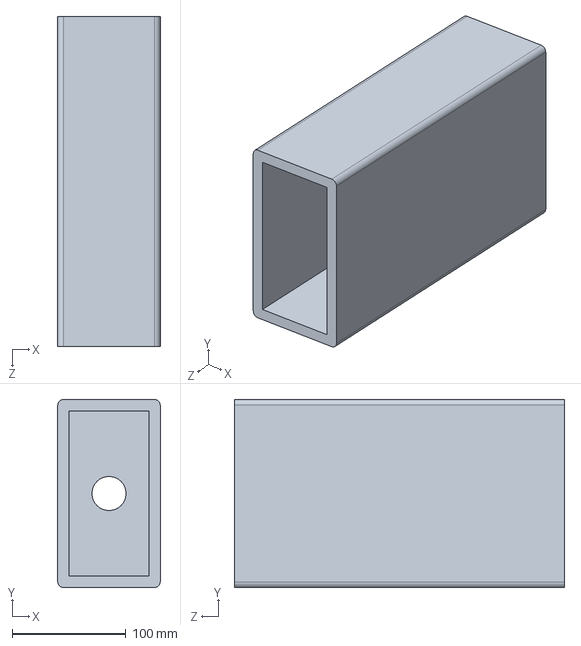
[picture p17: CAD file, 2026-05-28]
mechanical/new_balancerobot_concept/sldprt/몸통.SLDPRT
90.0 x 165.0 x 290.0 mm

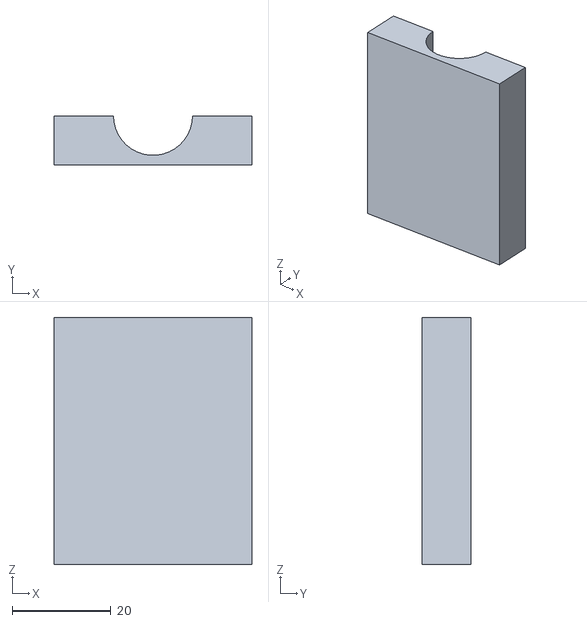
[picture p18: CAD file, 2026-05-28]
mechanical/new_balancerobot_concept/stl/바퀴 축실험.STL
40.0 x 10.0 x 50.0

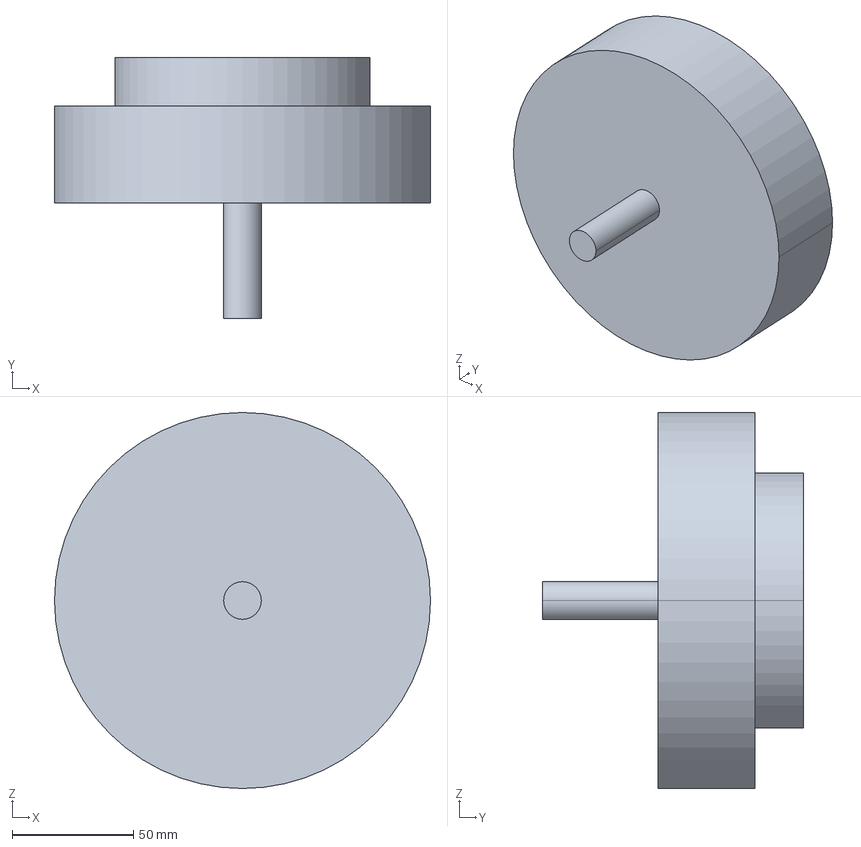
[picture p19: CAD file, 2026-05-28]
mechanical/new_balancerobot_concept/stp/balancing robot_wheel.stp
155.0 x 107.5 x 155.0 mm

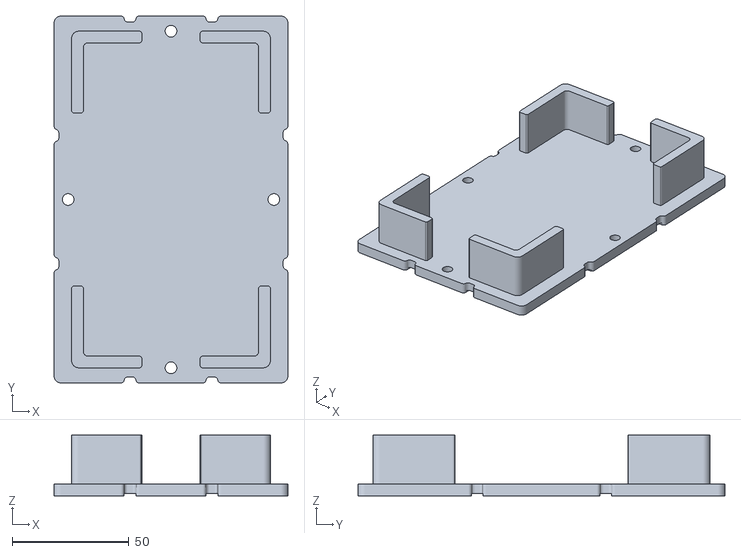
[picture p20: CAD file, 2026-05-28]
mechanical/print_ready/battery_plate.stl
100.0 x 157.0 x 26.0

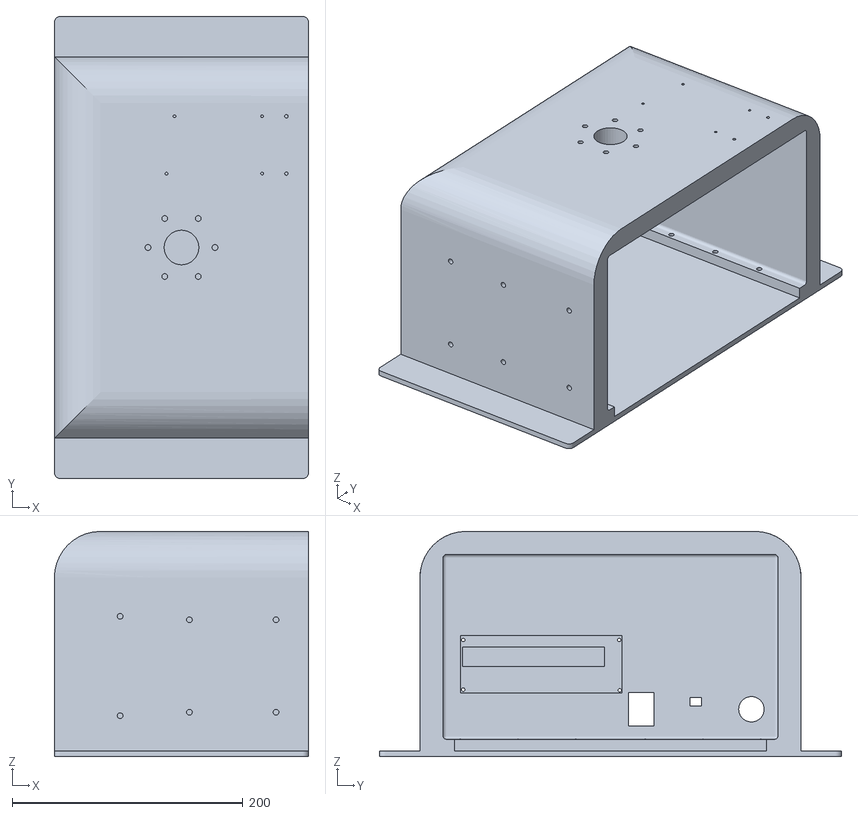
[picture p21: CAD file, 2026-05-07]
ros_ws/src/balance_robot_description/stl/body_side.stl
220.0 x 400.0 x 195.0

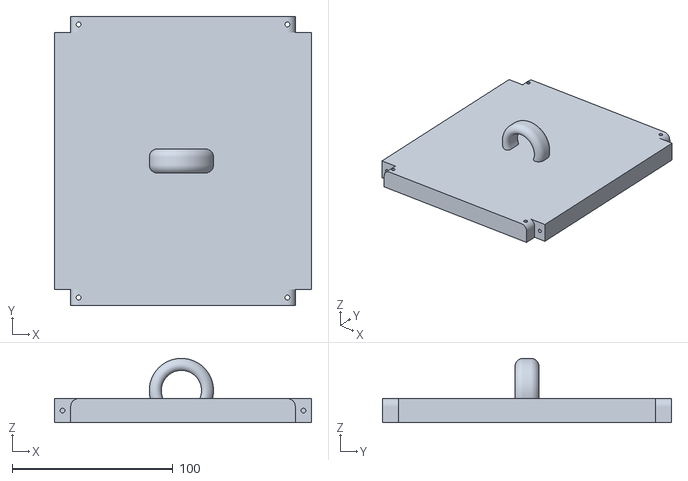
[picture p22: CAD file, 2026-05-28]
mechanical/head_sensor_mount/Head_ver_top.stl
160.0 x 180.0 x 40.0

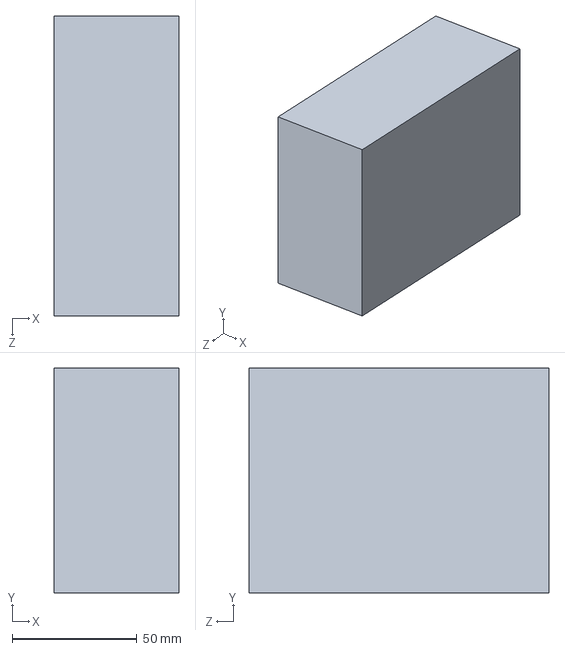
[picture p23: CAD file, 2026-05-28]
mechanical/new_balancerobot_concept/sldprt/ajfl.SLDPRT
50.0 x 90.0 x 120.0 mm

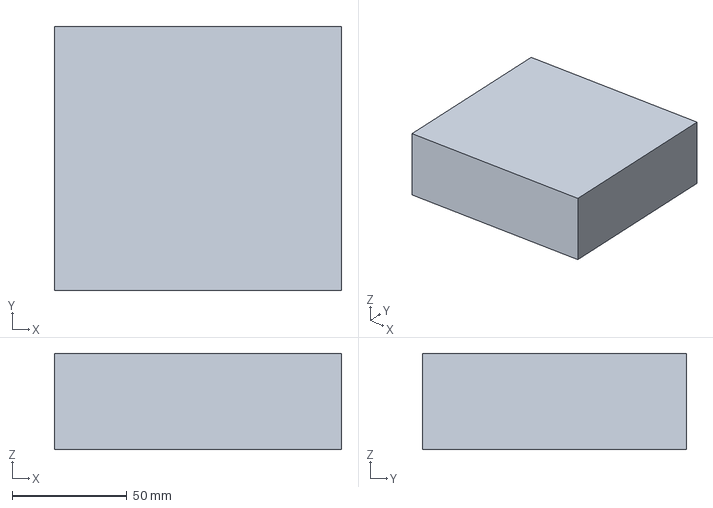
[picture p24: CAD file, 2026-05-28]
mechanical/new_balancerobot_concept/stp/balancing robot_intel.stp
125.0 x 115.0 x 42.0 mm

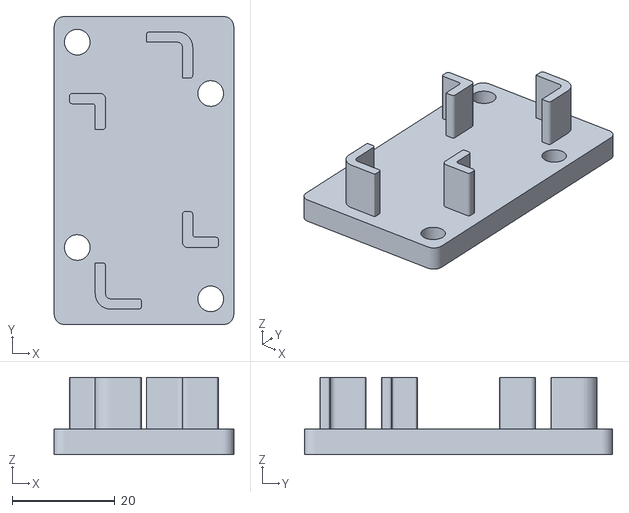
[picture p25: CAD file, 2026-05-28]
mechanical/print_ready/resis_plate.stl
35.0 x 60.0 x 15.0

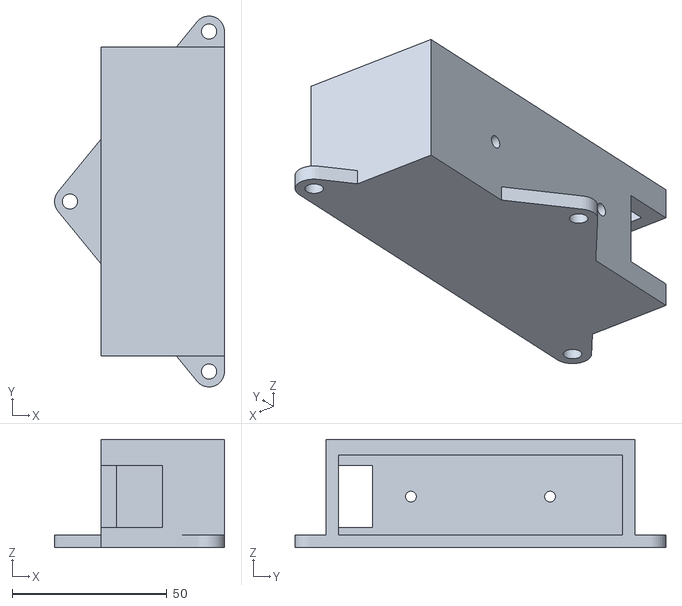
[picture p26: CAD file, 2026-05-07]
ros_ws/src/balance_robot_description/stl/gemini335_case.stl
55.0 x 120.0 x 35.0

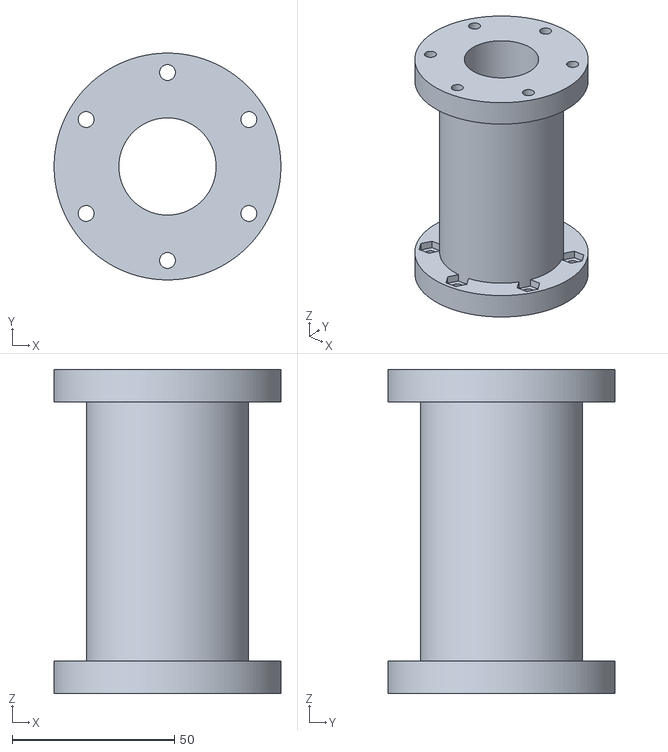
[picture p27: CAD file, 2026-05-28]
mechanical/head_sensor_mount/robot-neck.stl
70.0 x 70.0 x 100.0

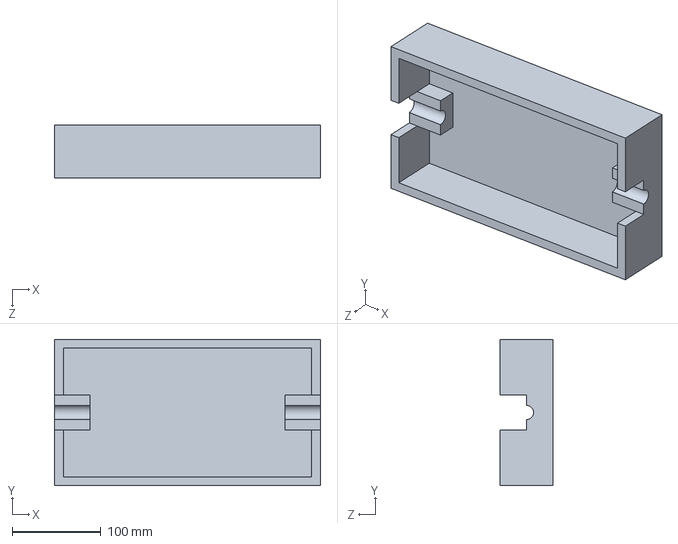
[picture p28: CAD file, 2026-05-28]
mechanical/new_balancerobot_concept/sldprt/밑면아래.SLDPRT
300.0 x 165.0 x 60.0 mm

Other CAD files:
mechanical/print_ready/balancing robot_package_ver2.stl
ros_ws/src/balance_robot_description/stl/head_top.stl
mechanical/head_sensor_mount/gemini335_case.stl
mechanical/new_balancerobot_concept/sldprt/목.SLDPRT
mechanical/head_sensor_mount/Head_ver2.CATPart
mechanical/head_sensor_mount/Head_ver2.stl
mechanical/head_sensor_mount/Head_ver_re1.CATPart
mechanical/head_sensor_mount/Head_ver_top.CATPart
mechanical/head_sensor_mount/balancing_assemble_ver1.CATProduct
mechanical/head_sensor_mount/gemini335_case.CATPart
mechanical/head_sensor_mount/lidar_case_ver2.CATPart
mechanical/head_sensor_mount/lidar_case_ver2.stl
mechanical/head_sensor_mount/robot-neck.CATPart
mechanical/head_sensor_mount/robot-neck_in.CATPart
mechanical/head_sensor_mount/robot-neck_in.stl
mechanical/new_balancerobot_concept/sldprt/balancing robot_wheel.SLDPRT
mechanical/new_balancerobot_concept/sldprt/밑면위.SLDPRT
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

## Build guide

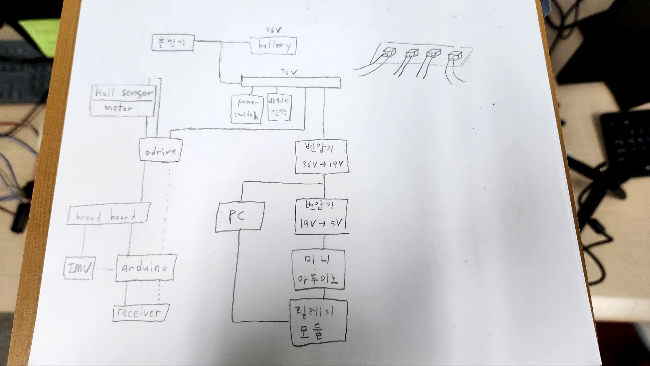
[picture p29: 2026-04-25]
media/hardware/wiring_hand_sketch.jpg

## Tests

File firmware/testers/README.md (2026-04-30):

# Bridges And Testers

This folder contains Arduino sketches that supported testing, integration, or bridging workflows.

The clearest Arduino-to-ROS example here is `rc_to_ros_cmd_vel_bridge.ino`, which uses `rosserial` (`ros.h`) to publish a `geometry_msgs/Twist` command from RC receiver PWM input.

- [`rc_to_ros_cmd_vel_bridge.ino`](rc_to_ros_cmd_vel_bridge.ino): RC PWM input to ROS `cmd_vel` bridge used as a tester for ROS-side experiments
- [`hall_sensor_test`](hall_sensor_test/hall_sensor_test.ino): three-line BLDC hall sensor state and illegal-state counter, based on the ChIMP hall test approach
- [`motor_current_test`](motor_current_test/motor_current_test.ino): direct ODrive current command bench test for one or both motors, based on the ChIMP motor test command workflow
- [`odrive_receiver_test`](odrive_receiver_test/odrive_receiver_test.ino): ODrive current-control test driven by RC receiver PWM inputs, adapted from HoverBot's ODrive test workflow
- [`receiver_pwm_test`](receiver_pwm_test/receiver_pwm_test.ino): FrSky receiver PWM pulse-width inspection sketch, based on HoverBot's receiver test workflow
- [`THIRD_PARTY_NOTICES.md`](THIRD_PARTY_NOTICES.md): attribution and license notes for referenced public test code

These files are useful for subsystem testing, but they are not the main physical balancing controller.

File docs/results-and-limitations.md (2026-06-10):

# Results And Limitations

English | [한국어](ko/results-and-limitations.md)

This page separates the finished results, the simulation-side results, the real-world integration experiments, and the parts that should be treated as future work.

## Project Result Snapshot

| Area | Result | Notes |
| --- | --- | --- |
| Physical balance duration | About 1 hour | Real robot standing balance under Arduino control |
| Physical driving | 10 m hallway driving | Real robot driving while balancing |
| Obstacle driving | Completed on a simple indoor obstacle course | Shown through the obstacle-course demo media |
| ROS/Gazebo navigation | Robot motion checked through the navigation command path and public depth-navigation capture | High-level commands were routed through `/before_vel` before final `/cmd_vel` |
| ROS/Gazebo SLAM | Map generation checked | Depth SLAM workflow was used for map-generation testing |
| Arduino-to-ROS bridge | `/imu`, `/odom`, and `cmd_vel` checked with `rostopic echo` | rosserial-style bridge sketches are kept in firmware and archive folders |

## Evidence Map

| Area | Environment | Evidence | How to read it |
| --- | --- | --- | --- |
| Physical balancing and RC driving | Real robot | [`physical_balance_controller.ino`](../firmware/physical_balance_controller/physical_balance_controller.ino), hallway and obstacle-course demo media | Completed real-world result |
| RC receiver and command handling | Real robot | [`receiver_pwm_test.ino`](../firmware/testers/receiver_pwm_test/receiver_pwm_test.ino), [`rc_to_ros_cmd_vel_bridge.ino`](../firmware/testers/rc_to_ros_cmd_vel_bridge.ino) | Completed subsystem tests and bridge workflow |
| ODrive, hall feedback, and motor control | Real robot | [`motor_current_test.ino`](../firmware/testers/motor_current_test/motor_current_test.ino), [`odrive_receiver_test.ino`](../firmware/testers/odrive_receiver_test/odrive_receiver_test.ino), [`development-process.md`](development-process.md) | Completed bring-up path behind the physical controller |
| ROS balance simulation and tuning | Simulation | [`balance_robot_control`](../ros_ws/src/balance_robot_control), [`balance_robot_gazebo`](../ros_ws/src/balance_robot_gazebo), archived PID experiments | Completed software-side workflow |
| SLAM and navigation workflow | Simulation / integration | [`balance_robot_workflows`](../ros_ws/src/balance_robot_workflows), [`navigation`](../ros_ws/src/navigation), [`simulation_depth_navigation_views.png`](../media/process/simulation_depth_navigation_views.png), [`simulation_depth_navigation_demo.webm`](../media/process/simulation_depth_navigation_demo.webm), [`archive/ros_experiments/real_world_integration`](../archive/ros_experiments/real_world_integration/README.md) | Simulation result plus partial physical integration context |
| Sim2Real bridge | Simulation and real robot | [`sim2real.md`](sim2real.md), [`control_algorithm.md`](../firmware/physical_balance_controller/control_algorithm.md), [`ros_ws/README.md`](../ros_ws/README.md) | Transfer of design, command layering, and safety boundaries, not finished physical autonomy |

## Code-Defined Settings

| Area | Value | Why it matters |
| --- | --- | --- |
| Physical tilt cutoff | `30 deg` | Set just above the protection bracket contact angle of about `28 deg`, so the controller cuts motor output before a hard fall can damage the robot |
| ODrive current clamp | `+/-8 A` | Prevents extreme current commands during recovery or unstable states |
| Firmware target speed limit | `1.5 m/s` | This is a target limit in code, not a measured top speed |
| RC neutral deadband | `+/-50 us` | Prevents small PWM drift around neutral from becoming motion |
| RC neutral offsets | throttle `1488 us`, steering `1492 us` | The controller uses calibrated centers instead of assuming exact `1500 us` |
| RC filter alpha | throttle/steering `0.4`, engage `0.02` | Throttle and steering stay responsive while engage is filtered more strongly |
| Main balance gains | `K_theta=24`, `K_theta_dot=1.7`, `Ki=0` | Body angle and angular velocity balance feedback |
| Speed-loop gains | `Kp=1.2`, `Ki=0.1`, `Kd=7` | Converts target motion into a balance-compatible speed correction |
| ROS publish interval | `50 ms`, about `20 Hz` | ROS-enabled Arduino variant publishes `/imu` and `/odom` at a fixed interval |
| ROS LiDAR controller gains | `Kp_angle=6.0`, `Kd_angle=-0.75`, `Kp_speed=0.3` | Main LiDAR simulation controller setting |
| ROS depth controller gains | `Kp_angle=8.0`, `Kd_angle=-1.45`, `Kp_speed=0.4` | Depth-camera simulation controller setting |
| Bayesian tuning search | `Kp_angle 2.0-8.0`, `Kd_angle -2.0 to -0.05`, `Kp_speed 0.1-0.5` | PID tuning was explored with a defined search space |

## Summary

| Status | Area | What I can say honestly | Where to look |
| --- | --- | --- | --- |
| Finished | Physical self-balancing and RC driving | The real two-wheeled robot balanced for about 1 hour and drove through a 10 m hallway and obstacle course. | [`physical_balance_controller.ino`](../firmware/physical_balance_controller/physical_balance_controller.ino), [`physical_balance_hallway.gif`](../media/hero/physical_balance_hallway.gif), [`physical_balance_obstacle_course.gif`](../media/demos/physical_balance_obstacle_course.gif) |
| Finished | Arduino-to-ROS bridge tests | Arduino sketches published robot or command data into ROS, and `/imu`, `/odom`, and `cmd_vel` were checked with `rostopic echo`. | [`physical_balance_controller_ros.ino`](../firmware/physical_balance_controller_ros/physical_balance_controller_ros.ino), [`rc_to_ros_cmd_vel_bridge.ino`](../firmware/testers/rc_to_ros_cmd_vel_bridge.ino), [`archive/arduino_firmware`](../archive/arduino_firmware/README.md) |
| Finished | Hardware and subsystem bring-up | ODrive, BNO055, FrSky receiver, motor feedback, and the main power/control packaging were all brought up on the real robot. | [`hardware.md`](hardware.md), [`development-process.md`](development-process.md) |
| Built in simulation | ROS/Gazebo balancing workflow | The balancing robot was modeled and controlled in Gazebo with ROS control nodes. | [`ros_ws/README.md`](../ros_ws/README.md), [`balance_robot_control`](../ros_ws/src/balance_robot_control/README.md), [`balance_robot_workflows`](../ros_ws/src/balance_robot_workflows/README.md) |
| Built in simulation | Navigation command pipeline | Navigation output was routed through `/before_vel`, and robot motion through that path was checked. | [`ros_ws/README.md`](../ros_ws/README.md), [`navigation`](../ros_ws/src/navigation/README.md), [`simulation_depth_navigation_views.png`](../media/process/simulation_depth_navigation_views.png) |
| Built in simulation | SLAM and navigation workflow | Depth-camera SLAM workflow was used to check map generation. | [`robot_slam_depth.launch`](../ros_ws/src/balance_robot_workflows/launch/robot_slam_depth.launch), [`ros_ws/README.md`](../ros_ws/README.md), [`simulation_depth_navigation_demo.webm`](../media/process/simulation_depth_navigation_demo.webm) |
| Documented bridge | Sim2Real transfer | The simulation and hardware paths share robot form factor, command-layer separation, and a balance/safety boundary, while physical full autonomy remains unfinished. | [`sim2real.md`](sim2real.md) |
| Integration experiment | Real-world ROS camera/SLAM/navigation | Camera, TF, RViz, SLAM, and navigation bring-up traces exist for the physical robot side. | [`archive/ros_experiments/real_world_integration`](../archive/ros_experiments/real_world_integration/README.md) |
| Future work | End-to-end autonomous navigation on the physical robot | The next step would be a real balancing robot that maps, localizes, plans, and drives to goals fully on its own. | This page and [`README.md`](../README.md) |
| Future work | Fully reproducible hardware rebuild package | The repository explains the robot well, but it is not a complete manufacturing or wiring reproduction package. | [`hardware.md`](hardware.md), [`archive/README.md`](../archive/README.md) |

## How I Read The Result

The strongest part of this project is the physical balancing robot and the control work around it. The ROS side also matters because it shows simulation, navigation adaptation, tuning workflows, map-generation testing, and Arduino-to-ROS topic bridging.

The repository shows the full robotics process:

- low-level embedded balancing control
- noisy sensor and RC signal handling
- actuator and feedback bring-up
- ROS/Gazebo simulation and workflow composition
- navigation command adaptation for an unstable balancing platform
- sim-to-real command-layer transfer between Gazebo workflows and Arduino balance control
- real-world ROS integration experiments around camera, TF, and robot-state publishing

## Remaining Limits

- Full physical autonomous ROS navigation remains future work.
- Third-party ROS dependencies are documented but not vendored.
- Full-length original videos are replaced by lighter GIFs, stills, and a compact WebM simulation clip.
- Older workspaces are kept under `archive/`, not presented as the main runnable stack.

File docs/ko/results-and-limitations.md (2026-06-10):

# 결과와 한계

[English](../results-and-limitations.md) | 한국어

이 문서는 finished results, simulation-side results, real-world integration experiments, future work를 분리해서 설명합니다.

## Project Result Snapshot

| Area | Result | Notes |
| --- | --- | --- |
| Physical balance duration | 약 1시간 | Arduino control 아래 실제 로봇 standing balance |
| Physical driving | 10 m hallway driving | 균형을 유지하면서 실제 로봇 주행 |
| Obstacle driving | 간단한 실내 장애물 코스 완료 | Obstacle-course demo media로 확인 가능 |
| ROS/Gazebo navigation | Navigation command path와 public depth-navigation capture로 robot motion 확인 | High-level command가 final `/cmd_vel` 전에 `/before_vel`을 거치도록 구성 |
| ROS/Gazebo SLAM | Map generation 확인 | Depth SLAM workflow로 map-generation test 수행 |
| Arduino-to-ROS bridge | `/imu`, `/odom`, `cmd_vel`을 `rostopic echo`로 확인 | rosserial-style bridge sketch는 firmware와 archive folder에 보존 |

## Evidence Map

| Area | Environment | Evidence | How to read it |
| --- | --- | --- | --- |
| Physical balancing and RC driving | Real robot | [`physical_balance_controller.ino`](../../firmware/physical_balance_controller/physical_balance_controller.ino), hallway/obstacle-course demo media | Completed real-world result |
| RC receiver and command handling | Real robot | [`receiver_pwm_test.ino`](../../firmware/testers/receiver_pwm_test/receiver_pwm_test.ino), [`rc_to_ros_cmd_vel_bridge.ino`](../../firmware/testers/rc_to_ros_cmd_vel_bridge.ino) | Completed subsystem tests and bridge workflow |
| ODrive, hall feedback, and motor control | Real robot | [`motor_current_test.ino`](../../firmware/testers/motor_current_test/motor_current_test.ino), [`odrive_receiver_test.ino`](../../firmware/testers/odrive_receiver_test/odrive_receiver_test.ino), [`development-process.md`](development-process.md) | Physical controller 뒤의 completed bring-up path |
| ROS balance simulation and tuning | Simulation | [`balance_robot_control`](../../ros_ws/src/balance_robot_control), [`balance_robot_gazebo`](../../ros_ws/src/balance_robot_gazebo), archived PID experiments | Completed software-side workflow |
| SLAM and navigation workflow | Simulation / integration | [`balance_robot_workflows`](../../ros_ws/src/balance_robot_workflows), [`navigation`](../../ros_ws/src/navigation), [`simulation_depth_navigation_views.png`](../../media/process/simulation_depth_navigation_views.png), [`simulation_depth_navigation_demo.webm`](../../media/process/simulation_depth_navigation_demo.webm), [`archive/ros_experiments/real_world_integration`](../../archive/ros_experiments/real_world_integration/README.md) | Simulation result와 partial physical integration context |
| Sim2Real bridge | Simulation and real robot | [`sim2real.md`](sim2real.md), [`control_algorithm.md`](../../firmware/physical_balance_controller/control_algorithm.md), [`ros_ws/README.md`](../../ros_ws/README.md) | Design, command layering, safety boundary의 transfer이며, finished physical autonomy는 아님 |

## Code-Defined Settings

| Area | Value | Why it matters |
| --- | --- | --- |
| Physical tilt cutoff | `30 deg` | 보호 브래킷이 약 `28 deg`에서 바닥에 닿기 때문에, hard fall로 인한 손상 전에 motor output을 차단 |
| ODrive current clamp | `+/-8 A` | Recovery 또는 unstable state에서 과도한 current command를 방지 |
| Firmware target speed limit | `1.5 m/s` | 측정된 최고 속도가 아니라 code 안의 target limit |
| RC neutral deadband | `+/-50 us` | Neutral 주변의 작은 PWM drift가 motion으로 바뀌는 것을 방지 |
| RC neutral offsets | throttle `1488 us`, steering `1492 us` | 정확히 `1500 us`를 가정하지 않고 calibrated center 사용 |
| RC filter alpha | throttle/steering `0.4`, engage `0.02` | Throttle/steering은 responsive하게, engage는 더 강하게 filtering |
| Main balance gains | `K_theta=24`, `K_theta_dot=1.7`, `Ki=0` | Body angle과 angular velocity 기반 balance feedback |
| Speed-loop gains | `Kp=1.2`, `Ki=0.1`, `Kd=7` | Target motion을 balance-compatible speed correction으로 변환 |
| ROS publish interval | `50 ms`, about `20 Hz` | ROS-enabled Arduino variant가 `/imu`, `/odom`을 고정 주기로 publish |
| ROS LiDAR controller gains | `Kp_angle=6.0`, `Kd_angle=-0.75`, `Kp_speed=0.3` | Main LiDAR simulation controller setting |
| ROS depth controller gains | `Kp_angle=8.0`, `Kd_angle=-1.45`, `Kp_speed=0.4` | Depth-camera simulation controller setting |
| Bayesian tuning search | `Kp_angle 2.0-8.0`, `Kd_angle -2.0 to -0.05`, `Kp_speed 0.1-0.5` | PID tuning을 정의된 search space로 탐색 |

## Summary

| Status | Area | What I can say honestly | Where to look |
| --- | --- | --- | --- |
| Finished | Physical self-balancing and RC driving | 실제 2륜 로봇이 약 1시간 균형을 유지했고, 10 m hallway와 obstacle course를 주행했습니다. | [`physical_balance_controller.ino`](../../firmware/physical_balance_controller/physical_balance_controller.ino), [`physical_balance_hallway.gif`](../../media/hero/physical_balance_hallway.gif), [`physical_balance_obstacle_course.gif`](../../media/demos/physical_balance_obstacle_course.gif) |
| Finished | Arduino-to-ROS bridge tests | Arduino sketch가 robot/command data를 ROS로 publish했고, `/imu`, `/odom`, `cmd_vel`을 `rostopic echo`로 확인했습니다. | [`physical_balance_controller_ros.ino`](../../firmware/physical_balance_controller_ros/physical_balance_controller_ros.ino), [`rc_to_ros_cmd_vel_bridge.ino`](../../firmware/testers/rc_to_ros_cmd_vel_bridge.ino), [`archive/arduino_firmware`](../../archive/arduino_firmware/README.md) |
| Finished | Hardware and subsystem bring-up | ODrive, BNO055, FrSky receiver, motor feedback, main power/control packaging을 실제 로봇에서 bring-up했습니다. | [`hardware.md`](hardware.md), [`development-process.md`](development-process.md) |
| Built in simulation | ROS/Gazebo balancing workflow | Balancing robot을 Gazebo에서 model/control했습니다. | [`ros_ws/README.md`](../../ros_ws/README.md), [`balance_robot_control`](../../ros_ws/src/balance_robot_control/README.md), [`balance_robot_workflows`](../../ros_ws/src/balance_robot_workflows/README.md) |
| Built in simulation | Navigation command pipeline | Navigation output을 `/before_vel`로 routing했고, 그 path를 통한 robot motion을 확인했습니다. | [`ros_ws/README.md`](../../ros_ws/README.md), [`navigation`](../../ros_ws/src/navigation/README.md), [`simulation_depth_navigation_views.png`](../../media/process/simulation_depth_navigation_views.png) |
| Built in simulation | SLAM and navigation workflow | Depth-camera SLAM workflow로 map generation을 확인했습니다. | [`robot_slam_depth.launch`](../../ros_ws/src/balance_robot_workflows/launch/robot_slam_depth.launch), [`ros_ws/README.md`](../../ros_ws/README.md), [`simulation_depth_navigation_demo.webm`](../../media/process/simulation_depth_navigation_demo.webm) |
| Documented bridge | Sim2Real transfer | Simulation과 hardware path는 robot form factor, command-layer separation, balance/safety boundary를 공유하지만 physical full autonomy는 unfinished로 둡니다. | [`sim2real.md`](sim2real.md) |
| Integration experiment | Real-world ROS camera/SLAM/navigation | Physical robot side의 camera, TF, RViz, SLAM, navigation bring-up trace가 존재합니다. | [`archive/ros_experiments/real_world_integration`](../../archive/ros_experiments/real_world_integration/README.md) |
| Future work | End-to-end autonomous navigation on the physical robot | 다음 단계는 실제 balancing robot이 map, localize, plan, goal driving까지 완전히 수행하는 것입니다. | 이 문서와 [`README.ko.md`](../../README.ko.md) |
| Future work | Fully reproducible hardware rebuild package | 저장소는 로봇을 잘 설명하지만, 완전한 manufacturing/wiring reproduction package는 아닙니다. | [`hardware.md`](hardware.md), [`archive/README.md`](../../archive/README.md) |

## How I Read The Result

이 프로젝트에서 가장 강한 부분은 실제 balancing robot과 그 주변의 control work입니다. ROS 쪽도 중요합니다. Simulation, navigation adaptation, tuning workflow, map-generation testing, Arduino-to-ROS topic bridging을 보여주기 때문입니다.

이 저장소가 보여주는 전체 robotics process는 다음과 같습니다.

- low-level embedded balancing control
- noisy sensor와 RC signal handling
- actuator와 feedback bring-up
- ROS/Gazebo simulation과 workflow composition
- unstable balancing platform을 위한 navigation command adaptation
- Gazebo workflow와 Arduino balance control 사이의 sim-to-real command-layer transfer
- camera, TF, robot-state publishing 주변의 real-world ROS integration experiments

## Remaining Limits

- Full physical autonomous ROS navigation은 future work입니다.
- Third-party ROS dependencies는 documented but not vendored입니다.
- Full-length original video는 lighter GIF, still image, compact WebM simulation clip으로 대체했습니다.
- Older workspace는 main runnable stack이 아니라 `archive/` 아래에 보존했습니다.

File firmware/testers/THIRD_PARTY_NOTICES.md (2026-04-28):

# Third-Party Test References

The sketches in this folder include project-specific bring-up tests and tests adapted from MIT-licensed public robot projects.

## ChIMP

- Source: https://github.com/CharlestonRobotics/ChIMP/tree/master/tests
- License: MIT License
- Used for reference: hall sensor state counting and ODrive motor-current command test structure

## HoverBot

- Source: https://github.com/LuSeKa/HoverBot/tree/master/tests
- License: MIT License
- Used for reference: ODrive receiver integration testing and RC PWM receiver inspection

The test sketches in this repository are kept as evidence of subsystem bring-up workflows. Attribution is preserved so that the portfolio does not present borrowed test structure as unreferenced original work.

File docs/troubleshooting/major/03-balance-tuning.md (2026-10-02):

# From standing to driving: separate the test stages and control terms

[한국어](../../ko/troubleshooting/major/03-balance-tuning.md) | [All troubleshooting](../../troubleshooting.md)

> Wheel/motor bench checks and tethered physical tests preceded free driving. The final controller combines balance, speed, and steering correction. Photos establish the testing environment; code and demos establish implementation and final behavior.

## A fall did not identify a gain fault

Physical recovery depended on attitude reference, wheel feedback, motor response, mass distribution, and gains. Changing everything on the assembled robot made failure attribution difficult.

Standing still and remaining upright while driving/turning were also different requirements. Direct motion requests could conflict with the wheel effort needed for body recovery.

## The testing environment was staged

Wheel and motor bench test

*Wheel/motor/control electronics checked separately from the assembled robot.*

Tethered physical practice

*Support-line practice before free driving.*

These photos show subsystem checks and constrained full-body testing. They do not measure a particular gain's improvement, but they establish part of the physical testing process.

The documented progression includes component bring-up, tethered attitude/driving practice, and hallway/obstacle driving. A complete gain-change history is not retained; final settings should not be described as the values used at every stage.

## Balance, speed, and steering received different roles

The final code calculates three correction terms and mixes them into two motor-current requests:

```cpp
float balance_controller = K_theta/100 * theta - K_theta_dot/100 * theta_dot + Ki/100 * integral_error;

torque_input_0 = (balance_controller - speed_control - steering_controller);
torque_input_1 = (balance_controller - speed_control + steering_controller);
```

| Term | Information used | Problem addressed |
| --- | --- | --- |
| Balance | Body angle and angular rate | Body recovery and attitude changes |
| Speed | Target minus mean wheel speed | Difference between requested and actual motion |
| Steering | Steering input and yaw rate | Differential effort alongside common recovery effort |

Balance and speed terms enter both wheels in common; steering enters with opposite signs. This preserves a shared stabilizing component while adding turning effort.

Initial settings in the final sketch are balance `K_theta=24`, `K_theta_dot=1.7`, `Ki=0`, and speed `Kp=1.2`, `Ki=0.1`, `Kd=7`. The balance-integral path exists but contributes zero at this initial setting. Speed sums/differences are per update without explicit `dt` normalization; these numbers are not directly portable to a different controller timing model.

## Adjustable variables and output bounds were explicit

The serial interface separates attitude gains, upright reference, and speed gains:

| Key | Parameter | Investigation dimension |
| --- | --- | --- |
| `q` / `e` | `K_theta` / `K_theta_dot` | Recovery and angular-rate response |
| `r` | `imu_angle_offset` | Sensor reference versus physical upright |
| `a` / `s` / `d` | Speed P/I/D coefficients | Motion correction |

This is the implemented tuning interface, not a recovered chronological record of every key used.

Outgoing current requests are bounded to +/-8 A, speed correction to +/-6, and speed-integral state to +/-5. Body tilt beyond 30 degrees sets a flag used in motor-deactivation decisions.

The current implementation also leaves review points. Axis activation updates run at a 50 ms interval, while `ApplyMotorCommands()` itself has no activation-state condition. Excessive tilt returns early from balance calculation; output freshness and state-transition timing therefore need to be considered together. The code should not be described as an independent immediate current-transmission gate. Bracket contact is recorded near 28 degrees, so the 30-degree threshold also does not guarantee pre-contact protection.

## Final motion is visible; each change's contribution needs separate evidence

Physical hallway driving

*The Arduino-controlled robot maintaining balance while moving.*

An [obstacle-course demo](../../../media/demos/physical_balance_obstacle_course.gif) is also available. The [result document](../../results-and-limitations.md) reports about one hour of balance and 10 m hallway driving. The GIF demonstrates motion; it is not a full-duration recording that independently measures the one-hour result.

The case connects **subsystem checks → constrained physical tests → combined control terms → final driving**. Attributing success to a single gain or quantifying a reduction in falls would require repeat-test data.

## Related code and records

- Bench/tether photos above: physical process evidence.
- [Controller](../../../firmware/physical_balance_controller/physical_balance_controller.ino): terms, mixing, tuning functions, and bounds.
- [Control algorithm](../../../firmware/physical_balance_controller/control_algorithm.md): overall signal/control flow.
- [Hallway](../../../media/hero/physical_balance_hallway.gif) / [obstacle demo](../../../media/demos/physical_balance_obstacle_course.gif): final behavior.
- [Results and limitations](../../results-and-limitations.md): reported duration and driving scope.

Synchronized pitch, wheel speed, current request, loop duration, and gain-change logs would extend the explanation from successful motion to the contribution of each adjustment.

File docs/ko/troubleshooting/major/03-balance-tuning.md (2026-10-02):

# 서는 로봇에서 주행하는 로봇으로: 시험 단계와 제어 항을 나누기

[English](../../../troubleshooting/major/03-balance-tuning.md) | [전체 트러블슈팅](../../troubleshooting.md)

> 모터 벤치 시험과 지지줄을 사용한 실물 시험을 거쳐 자세·속도·조향 보정을 결합했다. 시험 사진은 개발 환경을, 코드와 주행 영상은 구현 및 최종 동작을 보여준다.

## 넘어짐 하나로 게인의 문제를 단정하기 어려웠다

실물 로봇은 각도 오차뿐 아니라 바퀴 피드백, IMU 기준점, 모터 응답, 중량 배치의 영향을 함께 받았다. 작은 변경에도 복원 반응이 달라졌기 때문에 전체 로봇에서 모든 변수를 동시에 조정하면 실패 원인을 추적하기 어려웠다.

또한 제자리에서 서는 것과 전진·회전하면서 서는 것은 다른 요구였다. 이동 명령을 모터에 그대로 전달하면 자세 복원에 필요한 동작과 충돌할 수 있었다.

## 시험 환경부터 나눴다

모터와 바퀴 벤치 시험

*모터·바퀴·제어 전자부를 완성 로봇과 분리해 확인한 벤치 시험 사진.*

지지줄을 사용한 실물 주행 연습

*자유 주행 전 단계에서 로봇에 지지줄을 연결한 시험 사진.*

두 사진은 각각 부품 수준의 확인과 완성 로봇 시험 환경을 보여준다. 특정 게인의 전후 성능을 비교하는 데이터는 아니지만, 전체 로봇을 처음부터 자유 낙하 상태로 시험하지 않았다는 과정의 근거가 된다.

작업은 부품별 구동 확인, 지지줄을 사용한 자세·주행 시험, 복도·장애물 주행으로 이어졌다. 모든 단계의 게인 변경 이력이 보존된 것은 아니므로, 현재 설정을 처음부터 사용한 값처럼 설명하지 않는다.

## 자세·속도·조향에 각각 어떤 역할을 주었는가

최종 코드는 세 보정 항을 만든 뒤 두 모터 전류 요청으로 혼합한다.

```cpp
float balance_controller = K_theta/100 * theta - K_theta_dot/100 * theta_dot + Ki/100 * integral_error;

torque_input_0 = (balance_controller - speed_control - steering_controller);
torque_input_1 = (balance_controller - speed_control + steering_controller);
```

| 항목 | 사용하는 정보 | 이 항이 맡은 문제 |
| --- | --- | --- |
| 자세 보정 | 몸체 기울기 `theta`, 각속도 `theta_dot` | 몸체 복원과 급격한 자세 변화 대응 |
| 속도 보정 | 목표 속도와 좌우 바퀴 평균 속도의 차이 | 주행 요구와 현재 이동 상태의 차이 보정 |
| 조향 보정 | steering 입력, yaw rate | 공통 자세 보정에 좌우 차동 성분 추가 |

자세와 속도 항은 두 바퀴에 공통으로 들어가고, 조향 항은 반대 부호로 들어간다. 이 혼합 구조는 전진·회전 명령을 서로 독립적인 좌우 모터 명령으로 바로 사용하는 방식과 차이가 있다.

최종 초기값은 자세 `K_theta=24`, `K_theta_dot=1.7`, `Ki=0`, 속도 `Kp=1.2`, `Ki=0.1`, `Kd=7`이다. 자세 적분항은 식에는 있지만 초기 `Ki=0`이므로 이 설정에서는 출력에 기여하지 않는다. 속도 적분·차분은 갱신마다 계산하며 명시적인 `dt` 보정은 없다. 따라서 수치만 다른 제어기에 그대로 옮길 수 있는 게인은 아니다.

## 조정할 수 있는 변수와 출력의 한계를 정했다

시리얼 튜닝 인터페이스는 자세 게인, 각속도 게인, 직립 오프셋, 속도 게인을 각각 바꾸는 함수에 연결된다.

| 명령 키 | 조정 항목 | 구분하려는 영향 |
| --- | --- | --- |
| `q` / `e` | `K_theta` / `K_theta_dot` | 자세 복원과 각속도 반응 |
| `r` | `imu_angle_offset` | 센서 기준과 실제 직립점의 차이 |
| `a` / `s` / `d` | 속도 P/I/D 계수 | 이동 요구에 대한 보정 |

이는 당시 각 키를 어느 순서로 조정했는지에 대한 로그가 아니라, **코드에 남아 있는 변수 분리와 조정 수단**이다.

출력 제한도 제어식과 함께 적용했다. 전류 요청은 ±8 A, 속도 보정 출력은 ±6, 속도 적분 상태는 ±5로 제한한다. 기울기 절댓값이 30°를 넘으면 tilt 상태를 설정하고 ODrive 비활성화 판단에 사용한다.

현재 구현에서 확인할 개선점도 있다. 축 활성 상태 갱신은 50 ms 주기이며, `ApplyMotorCommands()` 자체에는 활성 상태를 검사하는 조건문이 없다. 기울기 초과 시 자세 계산은 조기 반환하므로 최신 출력 계산과 축 상태 전환 시점을 함께 검토해야 한다. 이 구조를 “기울기 초과 즉시 독립적으로 전류 송신을 차단한다”는 보장으로 확대하지 않는다. 보호 구조물 접촉은 약 28°로 기록되어 있어 30° 임계값도 접촉 전 차단 보장은 아니다.

## 최종 주행은 보여줄 수 있지만, 각 변경의 효과는 따로 봐야 한다

실물 로봇 복도 주행

*Arduino 제어로 실물 로봇이 균형을 유지하며 이동하는 공개 데모.*

[장애물 주행 데모](../../../../media/demos/physical_balance_obstacle_course.gif)도 남아 있다. [결과 문서](../../results-and-limitations.md)에는 약 1시간 균형 유지와 10 m 복도 주행이 기록되어 있다. GIF는 동작을 확인하는 자료이며 1시간 유지 시간을 직접 측정할 수 있는 전체 영상은 아니다.

이 사례에서 보여줄 수 있는 것은 **부품 시험 → 제한된 실물 시험 → 자세·속도·조향 통합 → 최종 주행**의 연결이다. 어떤 게인 하나가 성공을 만들었는지, 전도율이 얼마나 줄었는지는 별도의 반복 시험 데이터가 있어야 판단할 수 있다.

## 관련 코드와 기록

- 위 벤치·지지줄 사진: 시험 단계의 실물 근거.
- [최종 제어기](../../../../firmware/physical_balance_controller/physical_balance_controller.ino): 보정 항, 혼합식, 튜닝 함수, 출력 제한.
- [제어 알고리즘](../../../../firmware/physical_balance_controller/control_algorithm.md): 전체 신호·제어 흐름.
- [복도 주행](../../../../media/hero/physical_balance_hallway.gif) / [장애물 주행](../../../../media/demos/physical_balance_obstacle_course.gif): 최종 동작.
- [결과와 한계](../../results-and-limitations.md): 보고된 유지 시간과 주행 범위.

추가로 pitch·바퀴 속도·전류 요청·루프 시간·게인 변경 시점을 동기화한 로그가 있으면, “동작했다”에서 “왜 이 조정이 효과가 있었는가”까지 설명 범위를 넓힐 수 있다.

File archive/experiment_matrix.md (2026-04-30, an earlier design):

# Experiment Matrix

| Topic | Status | Main path | Evidence type |
| --- | --- | --- | --- |
| Physical balancing | Confirmed | [`firmware/physical_balance_controller`](../firmware/physical_balance_controller) | Firmware |
| RC driving while balancing | Confirmed | [`firmware/physical_balance_controller`](../firmware/physical_balance_controller) | Firmware + public demo GIF |
| RC-to-ROS bridge | Confirmed | [`firmware/testers`](../firmware/testers) | Tester firmware |
| Simulation balancing | Confirmed | [`ros_ws/src/balance_robot_control`](../ros_ws/src/balance_robot_control) | ROS code |
| Simulation navigation | Confirmed | [`ros_ws/src/navigation`](../ros_ws/src/navigation) | ROS code |
| PID evolution | Recovered | [`archive/ros_experiments/pid_experiments`](ros_experiments/pid_experiments) | Archived ROS controller variants |
| Real-world SLAM setup | Recovered | [`archive/ros_experiments/real_world_integration`](ros_experiments/real_world_integration) | Archived ROS launch files |
| Trial-and-error notes | Recovered | [`archive/raw_documents`](raw_documents) | Summarized legacy source material |

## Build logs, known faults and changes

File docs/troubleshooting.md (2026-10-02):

# Troubleshooting: from observations to control and architecture changes

English | [한국어](ko/troubleshooting.md)

Unexpected wheel motion and falls did not have one cause. Separating RC input, motor drive, attitude reference, speed feedback, and ROS commands led to changes in both control and testing.

Each case connects **the problem → the investigation → the response → the changed interpretation → inspectable results**. Major cases concern safety and physical behavior; supporting cases explain the sensor, feedback, and software decisions behind them.

## Three cases to read first

| Case | Work performed | Inspectable evidence |
| --- | --- | --- |
| [Wheels moved without an intended command](troubleshooting/major/01-rc-pwm-spikes.md) | Isolate PWM inspection, investigate placement, change input handling | Tester output fields and final filter/deadband/engage logic |
| [Sudden motor acceleration](troubleshooting/major/02-odrive-runaway.md) | Separate RC/hall/direct-current paths, interpret firmware-change outcome | Four testers, state requests, current-request bounds |
| [From standing to driving](troubleshooting/major/03-balance-tuning.md) | Bench/tether tests, combine balance/speed/steering | Test photos, mixing equations, driving demos |

## Supporting cases

| Case | Decision demonstrated |
| --- | --- |
| [IMU zero versus upright reference](troubleshooting/supporting/01-imu-upright-reference.md) | Separate calibration from mechanical posture reference |
| [Speed-feedback handling](troubleshooting/supporting/02-wheel-speed-feedback.md) | Distinguish processing experiments from active code |
| [Navigation through balance control](troubleshooting/supporting/03-ros-command-path.md) | Separate high-level intent from low-level attitude control |

## Evidence scope

Tester output fields and excerpts establish implementation. Photos and short demos establish testing environments and visible behavior. Metal/foil observations and firmware-downgrade outcome come from existing project records; raw experiment logs are not published. Code-derived values are identified separately from measurements.

The repository reconstructs and organizes an earlier project. A tester's existence does not independently establish every historical test result. The cases focus on work and outcomes that can presently be inspected.

See the [control algorithm](../firmware/physical_balance_controller/control_algorithm.md) for complete equations, [results and limitations](results-and-limitations.md) for completion scope, and [Sim2Real](sim2real.md) for the simulation/hardware connection.

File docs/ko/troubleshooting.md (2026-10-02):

# 트러블슈팅: 관찰에서 제어·구조 변경까지

[English](../troubleshooting.md) | 한국어

이 프로젝트에서 바퀴의 비정상 움직임과 전도는 하나의 원인으로 설명되지 않았다. RC 입력, 모터 구동, 자세 기준, 속도 피드백, ROS 명령 경로를 나누어 확인하면서 제어와 시험 방법을 바꿨다.

각 사례는 **문제 상황 → 조사한 경로 → 실제 대응 → 판단의 변화 → 확인 가능한 결과**를 연결한다. 중요 사례는 안전과 실물 동작에 직접 영향을 준 조사이며, 보조 사례는 그 과정을 이해하는 데 필요한 센서·피드백·소프트웨어 설계다.

## 먼저 볼 세 가지 사례

| 사례 | 수행한 작업 | 관련 코드·자료 |
| --- | --- | --- |
| [조작하지 않았는데 바퀴가 움직였다](troubleshooting/major/01-rc-pwm-spikes.md) | 수신기 PWM 분리 관찰, 배치 조사, 입력 처리 변경 | PWM 테스터 출력 항목, 최종 필터·데드밴드·engage 로직 |
| [모터가 갑자기 가속했다](troubleshooting/major/02-odrive-runaway.md) | RC·홀센서·직접 전류 경로 분리, 펌웨어 변경 결과 해석 | 4개 테스터, 상태 전환·전류 제한 코드 |
| [서는 로봇에서 주행하는 로봇으로](troubleshooting/major/03-balance-tuning.md) | 벤치·지지줄 시험, 자세·속도·조향 통합 | 시험 사진, 혼합식, 복도·장애물 주행 영상 |

## 함께 읽을 보조 사례

| 사례 | 보여주는 판단 |
| --- | --- |
| [IMU의 0°가 로봇의 직립점은 아니었다](troubleshooting/supporting/01-imu-upright-reference.md) | 센서 보정과 기구 기준점 분리 |
| [속도 값이 튀면 모터 보정도 튄다](troubleshooting/supporting/02-wheel-speed-feedback.md) | 샘플 처리 실험과 현재 활성 경로 구분 |
| [Navigation 명령을 밸런스 제어기에 통과시켰다](troubleshooting/supporting/03-ros-command-path.md) | 상위 이동 의도와 하위 자세 제어 책임 분리 |

## 근거의 범위

테스터 출력 열과 코드 발췌는 저장소 구현을 보여준다. 사진과 짧은 영상은 시험 환경과 동작을 보여준다. 금속·포일 실험 및 펌웨어 다운그레이드 결과는 기존 작업 기록에 근거하며, 공개된 원시 실험 로그는 없다. 코드에서 계산한 값은 실측값과 구분해 표시했다.

저장소는 원래 프로젝트의 코드와 자료를 복원·정리한 개발 기록이다. 테스터가 존재한다는 사실만으로 모든 역사적 시험 결과가 입증되는 것은 아니다. 각 문서는 현재 확인할 수 있는 작업과 결과를 중심으로 읽도록 구성했다.

전체 수식은 [제어 알고리즘](../../firmware/physical_balance_controller/control_algorithm.md), 프로젝트의 완료 범위는 [결과와 한계](results-and-limitations.md), 시뮬레이션과 실물의 연결은 [Sim2Real](sim2real.md)에서 확인할 수 있다.

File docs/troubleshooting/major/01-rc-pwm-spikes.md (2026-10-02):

# The wheels moved without an intended command: inspect the RC input first

[한국어](../../ko/troubleshooting/major/01-rc-pwm-spikes.md) | [All troubleshooting](../../troubleshooting.md)

> I separated FrSky X8R PWM inspection from motor control, investigated placement-dependent behavior, and changed how input was interpreted. Channel-specific filters, neutral deadband, and engage persistence remain in the final code.

## Wheel motion alone did not identify a gain problem

During physical bring-up, the wheels sometimes twitched without an intended command. The visible symptom was motor motion, but that did not establish a fault in the balance gains. A bad receiver command and a motor path reacting incorrectly to a valid command required different checks.

I moved the observation point from wheel motion to **the PWM pulse width entering Arduino**. If the input itself jumped, changing balance gains would not address the command interpretation problem.

## What the receiver-only test exposed

The [receiver tester](../../../firmware/testers/receiver_pwm_test/receiver_pwm_test.ino) inspects throttle, steering, and engage without driving ODrive. It stores the rising-edge time and uses `micros()` to calculate pulse width at the falling edge. At 115200 baud, it prints approximately every 20 ms:

```text
throttle_us    steering_us    engage_us
```

These are **the tester's output column names**, not a reconstructed measurement log.

Separating the channels provides a way to compare motion intent with motor-activation intent. The print interval does not capture every individual pulse fault, but the sketch establishes an observation point independent of motor response.

The existing project notes report these observations:

| Check | Recorded observation | Consequence for the investigation |
| --- | --- | --- |
| Arduino PWM inspection | Pulse-width jumps were observed | Balance control alone could not explain the problem |
| Connections and wiring | Connections/routing were reworked repeatedly | Inspect the input path separately |
| Receiver proximity to metal | Symptoms changed with metal proximity | Retain receiver/antenna placement as a cause candidate |
| Aluminum-foil experiment | Spikes became worse | No basis for adopting foil as the solution |

The foil experiment was an unsuccessful mitigation. It supported investigating conductive surroundings, but did not distinguish RF effects from PWM wiring noise.

## How input interpretation changed

Placement and close signal-ground routing were investigated as hardware mitigations. Software handling then addressed distinct input behaviors:

| Handling in the final sketch | Setting | Purpose |
| --- | --- | --- |
| Throttle/steering low-pass filtering | `alpha=0.4` | Reduce the effect of brief changes on motion requests |
| Engage low-pass filtering | `alpha=0.02` | Apply stronger smoothing to activation input |
| Neutral deadband | Zero input for deviations below `50 us` | Avoid interpreting small neutral drift as motion |
| Engage persistence | Counter updated with the 50 ms activation task | Reduce reliance on one activation decision |

The throttle recurrence is:

```cpp
filtered_throttle_pwm = kAlpha_1 * throttle_pwm + (1.0 - kAlpha_1) * filtered_throttle_pwm;
```

Engage uses a smaller coefficient than throttle/steering. The implementation distinguishes responsiveness of motion input from stability of activation decisions.

The persistence counter rises or falls, is constrained to `-3..3`, and declares engage when positive. It is therefore not a simple guarantee of exactly three consecutive samples before activation.

Neutral is not universally assumed to be 1500 us: the deadband centers are throttle 1488 us and steering 1492 us. Throttle normalization still uses 1491 us, so those references are not fully unified.

## The lesson was a criterion for trusting input

A received value is not automatically a valid operator intention. Neutral drift, a short spike, and an activation request need different treatment.

The investigation connected placement-dependent observations with channel-specific input processing. Hardware checks explained why the input path deserved attention; filters, deadband, and persistence reduced the influence of remaining variations.

## Related code and records

- [Receiver tester](../../../firmware/testers/receiver_pwm_test/receiver_pwm_test.ino): pulse-width measurement and output fields.
- [Physical controller](../../../firmware/physical_balance_controller/physical_balance_controller.ino): filter constants, deadband, and engage counter.
- [Development process](../../development-process.md): receiver and wiring investigation context.

Implementation is inspectable in code. Metal/foil outcomes come from existing project notes; raw logs and comparative spike rates are not published. This supports describing the response, not a numerical noise-reduction claim.

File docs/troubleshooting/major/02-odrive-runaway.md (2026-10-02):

# Sudden motor acceleration: isolate the ODrive path

[한국어](../../ko/troubleshooting/major/02-odrive-runaway.md) | [All troubleshooting](../../troubleshooting.md)

> I investigated intermittent uncontrolled motion by separating RC input, hall feedback, command conversion, and direct motor requests. Existing notes report symptom disappearance after firmware downgrade; the repository retains the corresponding testers and state/current-limit implementation.

## RC noise did not explain every motor symptom

The ODrive path sometimes accelerated unexpectedly or failed to stop normally. RC spikes also existed, but they did not explain all motor behavior. Adjusting gains on the complete robot would mix input interpretation, hall feedback, controller response, and ODrive settings.

The investigation became **which paths can be checked independently**, rather than treating runaway as one undifferentiated robot failure.

## Four checks reduced the number of coupled variables

| Check | Inspectable output | Cause candidate being separated |
| --- | --- | --- |
| Hall-only test | A/B/C state, transition count, illegal-state count | Sensor connection/state signals |
| Receiver-only test | Throttle/steering/engage pulse widths | RC input itself |
| Receiver–ODrive test | PWM, left/right current requests, active state | Input-to-current conversion |
| Direct-current test | Per-axis requests, stop and IDLE requests | Motor command path without RC or IMU |

The hall tester reads A0/A1/A2 and classifies all-low or all-high states as illegal. Its output fields are:

```text
hall_a    hall_b    hall_c    state    transitions    illegal
```

Those counters provide an observation method, not proof of a particular measured illegal-state count. Existing notes describe continuing the investigation after hall checks did not identify the culprit.

## Removing input paths narrowed the question

The [direct-current tester](../../../firmware/testers/motor_current_test/motor_current_test.ino) uses neither RC nor IMU. Serial commands request current on one/both axes and distinguish zero-current requests from IDLE requests.

| Command | What the code does |
| --- | --- |
| `m <axis> <amps>` | Requests bounded current on one axis |
| `b <amps>` | Requests current on both axes |
| `s` | Requests 0 A on both axes |
| `d` | Requests 0 A, then IDLE on both axes |

That separation makes receiver-input faults and motor-path behavior independently testable. This repository reconstructs and organizes earlier work; today's tester files alone do not recover every historical test result.

The existing investigation notes report that **firmware downgrade removed the runaway symptom**. This narrowed suspicion toward firmware/hall-drive compatibility. Exact before/after versions and a firmware-level fault trace are absent, so the result is an empirical resolution rather than a fully established internal bug.

## Motor state and command bounds remained explicit

The final sketch retains `EngageMotors()` for axis-state requests and `ApplyMotorCommands()` for current-request bounds:

```cpp
float current_command_0 = constrain(torque_input_0, -kMaxAbsCurrent, kMaxAbsCurrent);
float current_command_1 = constrain(torque_input_1, -kMaxAbsCurrent, kMaxAbsCurrent);
```

With `kMaxAbsCurrent=8.0`, outgoing Arduino requests are bounded to +/-8 A. Engage and tilt conditions participate in requests to switch between `IDLE` and `CLOSED_LOOP_CONTROL`.

A 0 A request, an IDLE request, and power disconnection are different actions. These files show command bounds and state logic; they are not actual-current measurements or independent containment of every ODrive fault.

## Resolution and root cause became separate conclusions

Firmware change affected the symptom. Subsystem tests also left a method for investigating recurrence under fewer coupled variables.

## Related code and records

- [Hall tester](../../../firmware/testers/hall_sensor_test/hall_sensor_test.ino): state and counters.
- [Receiver tester](../../../firmware/testers/receiver_pwm_test/receiver_pwm_test.ino): input pulse widths.
- [Receiver–ODrive tester](../../../firmware/testers/odrive_receiver_test/odrive_receiver_test.ino): PWM/current relationship.
- [Current tester](../../../firmware/testers/motor_current_test/motor_current_test.ino): requests without RC/IMU.
- [Physical controller](../../../firmware/physical_balance_controller/physical_balance_controller.ino): limits and state requests.

Downgrade outcome is supported by existing notes. Version records, repeated identical-condition tests, and ODrive error-state logs would strengthen the connection between firmware change and outcome.

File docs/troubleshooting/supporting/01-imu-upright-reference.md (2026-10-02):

# IMU zero was not the robot's upright reference

[한국어](../../ko/troubleshooting/supporting/01-imu-upright-reference.md) | [All troubleshooting](../../troubleshooting.md)

> Sensor calibration and mechanical upright reference were treated separately. The final attitude calculation applies an explicit offset.

## Persistent correction could involve the reference, not only gains

If the IMU angle differs from the useful physical upright posture, the controller continually corrects toward the wrong point. This motivated calibration/reference management in the existing project notes. Sensor startup state, mounting direction, and physical equilibrium therefore needed attention before gain changes alone could explain the behavior.

## Sensor state and upright reference were separated

The sketch halts on BNO055 initialization failure and provides calibration-status and EEPROM save/load helpers. A separate `imu_angle_offset` adjusts the control reference.

| Code path | What it checks or changes |
| --- | --- |
| `bno.begin()` | Sensor initialization |
| `checkIMUCalibration()` | System/gyro/accel/magnetometer calibration status |
| `saveCalibration()` / `loadCalibration()` | Store/restore 22 bytes of calibration data |
| `SetImuAngleOffset()` | Adjust the posture reference used by control |

Sensor calibration data and body upright offset are different quantities. Calibrating the sensor does not remove every mounting/equilibrium difference.

## What is active in the final sketch

```cpp
float imu_angle_offset = 3.5;
```

The angle calculation is:

```cpp
theta = imu_enabled * (euler_angles.y() + imu_angle_offset);
```

With IMU enabled, corrected zero corresponds to raw y-angle -3.5 degrees. **That is a code-derived reference, not a measured posture log.** The tilt-threshold check uses the same offset.

The startup calls to `loadCalibration()` and `checkIMUCalibration()` are commented out. Helper availability therefore does not establish automatic restoration/status reporting on each boot.

## The reference became an explicit input condition

Offset adjustment is exposed separately through serial key `r`. This distinguishes insufficient recovery response from a different intended equilibrium point.

## Related code and records

Inspect `setup()`, `checkIMUCalibration()`, `SetImuAngleOffset()`, and `BalanceController()` in the [physical controller](../../../firmware/physical_balance_controller/physical_balance_controller.ino). Offset implementation is inspectable; fixed-posture restart logs are not published, so a numerical repeatability improvement is not established.

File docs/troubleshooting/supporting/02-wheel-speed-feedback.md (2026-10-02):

# A speed spike changes motor correction: follow the feedback handling

[한국어](../../ko/troubleshooting/supporting/02-wheel-speed-feedback.md) | [All troubleshooting](../../troubleshooting.md)

> Archived code uses recent history and a median fallback for abrupt samples. The final sketch uses receive/parsing handling and bounded speed correction. Historical experiments and active processing are distinguishable.

## A feedback fault can affect the common motor effort

The speed loop subtracts mean wheel speed from target speed. Its correction enters both motor requests. One abnormal sample can therefore change the motor correction even without an operator-input change.

The question was **which samples should influence control**, not simply how to print wheel speed.

## Earlier code compared samples with recent history

The [legacy controller](../../../archive/arduino_firmware/legacy_balance_controller.ino) computes a threshold using the mean absolute magnitude of five recent values:

```cpp
return 3.0 * (sum / N);
```

An abrupt change beyond that threshold is replaced with the median of the new sample and two previous values:

```cpp
if (abs(phi_dot_counts_0 - prev_dot_0) > adaptive_threshold_dot_0) {
    phi_dot_counts_0 = median_phi_dot_0;
}
```

This experiments with history-dependent checks and a median fallback. The new sample also enters the threshold history; this is not evidence of a validated statistical outlier detector.

## Active processing differs from the archived experiment

| Path | Archived code | Final sketch |
| --- | --- | --- |
| Abrupt changes | History threshold and three-value median | Same path absent from the active loop |
| Receive handling | Position/speed inspection paths | Drain available bytes around two `parseFloat()` reads |
| Speed smoothing | Historical equations/settings | Recurrence retained, but `kAlpha_3=1` |
| Correction bounds | Historical control settings | Integral +/-5; speed output +/-6 |

At `kAlpha_3=1`, each new speed sample passes directly through. A variable called `filtered_phi_dot` does not establish active smoothing.

A `filterEncoderData()` helper also remains in the final file but is not called by active `BalanceController()`. Draining available bytes does not validate complete response framing, sample validity, or timeout outcomes.

## Measurement validity and output bounds solve different problems

Integral/output limits constrain correction magnitude. Outlier detection judges the sample itself. One does not establish the other.

Comparing versions shows feedback-processing experiments, while preventing the claim that every archived countermeasure is deployed.

## Related code and records

- [Legacy controller](../../../archive/arduino_firmware/legacy_balance_controller.ino): `updateThreshold()`, `getMedian()`, abrupt-sample replacement.
- [Final controller](../../../firmware/physical_balance_controller/physical_balance_controller.ino): receive/parsing, `kAlpha_3`, speed bounds.

The code establishes changes in processing. Synchronized raw responses, wheel speed, and current-request comparison logs are not published, so numerical vibration reduction is not claimed.

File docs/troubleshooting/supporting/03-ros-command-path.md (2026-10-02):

# Route navigation through the balancing controller

[한국어](../../ko/troubleshooting/supporting/03-ros-command-path.md) | [All troubleshooting](../../troubleshooting.md)

> In simulation, `move_base` output becomes motion intent. A balancing controller combines it with IMU/odometry feedback before publishing final `/cmd_vel`.

## Motion requests and attitude recovery share the wheels

Navigation asks for velocity toward a destination. A two-wheeled balancing robot also uses wheel motion to recover its body. Sending high-level velocity straight to the base can bypass the layer that reconciles those requirements.

This case concerns command architecture, rather than a separately recorded hardware failure.

## Navigation output was redirected first

[move_base.launch](../../../ros_ws/src/navigation/launch/move_base.launch) defaults its output destination to `/before_vel`:

```xml
<arg name="cmd_vel_topic" default="/before_vel" />
```

```xml
<remap from="cmd_vel" to="$(arg cmd_vel_topic)"/>
```

That topic carries target speed/turn input for the balancing controller rather than final base output.

## The balancing layer adds robot state

The [LiDAR simulation controller](../../../ros_ws/src/balance_robot_control/src/controllers/pid_control_before_vel_lidar.py) separates intent, feedback, and output:

| Topic | Role |
| --- | --- |
| `/before_vel` | Set desired speed/turn input |
| `/odom` | Update current speed |
| `/imu` | Calculate attitude and update control output |
| `/cmd_vel` | Publish calculated base command |

Speed error becomes desired lean, then is compared with actual pitch:

```python
speed_error = self.setpoint_speed - self.current_speed
self.setpoint_angle = self.Kp_speed * speed_error
angle_error = self.setpoint_angle - current_pitch_angle
output_angle = (self.Kp_angle * angle_error + self.Kd_angle * pitch_rate)
```

LiDAR-version control calculations execute in the IMU callback. A `rospy.Rate(200)` declaration alone does not establish a measured 200 Hz control frequency.

## Publisher/subscriber relationships matter more than names

The intended route is `move_base → /before_vel → balance_robot_control → /cmd_vel`. Launch remapping and controller subscriptions/publications together establish the implemented path.

Simulation navigation view

*Public depth-model simulation capture. The excerpts above are from the LiDAR variant; the image/video document the depth workflow.*

The model settings differ, but share the intent/final-output separation. On hardware, Arduino calculates ODrive current requests. Shared architecture and completed physical autonomy are different claims.

## Related code and records

- [move_base.launch](../../../ros_ws/src/navigation/launch/move_base.launch): navigation-output remapping.
- [LiDAR controller](../../../ros_ws/src/balance_robot_control/src/controllers/pid_control_before_vel_lidar.py): intent/state/output relationship.
- [Control package guide](../../../ros_ws/src/balance_robot_control/README.md): model variants and tuning paths.
- [Simulation clip](../../../media/process/simulation_depth_navigation_demo.webm): depth-workflow behavior.
- [Sim2Real scope](../../sim2real.md): physical autonomy remains integration work.

Inspect live publishers/subscribers with `rostopic info /before_vel` and `rostopic info /cmd_vel`. Public demos show simulation behavior, not finished autonomous navigation on the physical robot.

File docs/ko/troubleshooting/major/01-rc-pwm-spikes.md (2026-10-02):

# 조작하지 않았는데 바퀴가 움직였다: RC 입력부터 분리해 확인하기

[English](../../../troubleshooting/major/01-rc-pwm-spikes.md) | [전체 트러블슈팅](../../troubleshooting.md)

> FrSky X8R의 PWM을 모터 제어와 분리해 관찰하고, 배치에 따른 증상 변화와 중립값을 바탕으로 입력 처리 방식을 수정했다. 최종 코드에는 채널별 필터, 데드밴드, 활성화 지속성 검사가 남아 있다.

## 바퀴의 움직임만 보고 제어 게인을 바꿀 수는 없었다

실물 로봇을 구동하는 과정에서 조작 의도와 다르게 바퀴가 순간적으로 움직였다. 처음 보이는 현상은 모터의 움직임이었지만, 그 현상만으로 자세 제어가 잘못되었다고 판단하기는 어려웠다. 수신기가 잘못된 명령을 보내는 경우와 정상 입력을 받은 모터 경로가 잘못 반응하는 경우를 구분해야 했다.

그래서 확인 대상을 **바퀴 움직임에서 Arduino에 들어오는 PWM 펄스폭으로** 옮겼다. 입력 단계에서 신호가 튄다면 자세 제어를 다시 튜닝하기 전에 명령 해석부터 바로잡아야 하기 때문이다.

## 수신기 단독 시험으로 무엇을 보았는가

[수신기 테스터](../../../../firmware/testers/receiver_pwm_test/receiver_pwm_test.ino)는 ODrive 구동 없이 throttle, steering, engage의 펄스폭을 확인할 수 있도록 구성되어 있다. 상승 에지 시간을 저장하고 하강 에지까지의 시간 차를 `micros()`로 계산한다. 출력은 115200 baud에서 약 20 ms 간격으로 다음 열을 제공한다.

```text
throttle_us    steering_us    engage_us
```

이는 **테스터의 출력 열 이름**이다. 당시 측정값을 새로 재현한 로그는 아니다.

이렇게 채널을 나누면 throttle·steering의 변화는 이동 의도와, engage의 변화는 모터 활성화 판단과 연결해 볼 수 있다. 출력 간격은 약 20 ms이므로 모든 펄스의 이상을 빠짐없이 기록하는 장치는 아니지만, 모터 반응과 입력 신호를 분리해 확인할 수 있는 관찰 지점을 만든다.

기존 작업 기록에는 다음 관찰이 남아 있다.

| 확인한 조건 | 기록된 관찰 | 다음 판단 |
| --- | --- | --- |
| Arduino에서 수신기 PWM 확인 | 펄스폭이 갑자기 변하는 현상 확인 | 자세 제어만의 문제로 다룰 수 없음 |
| 배선·수신기 접속 수정 | 접속과 배선 조건을 여러 차례 변경 | 입력 경로의 상태를 따로 확인할 필요 |
| 금속 구조물과 수신기 위치 변경 | 금속 근접 여부에 따라 증상이 달라짐 | 수신기·안테나 배치를 원인 후보로 유지 |
| 알루미늄 포일 적용 | 신호 튐이 오히려 악화 | 포일 적용을 해결책으로 채택할 근거가 없음 |

특히 포일 실험은 예상한 방향으로 개선되지 않은 시도였다. 이 결과는 배치와 주변 전도성 물체가 영향을 준다는 단서였지만, RF 환경과 PWM 배선 노이즈 중 어느 것이 지배적인지는 이 기록만으로 확정할 수 없었다.

## 입력을 그대로 명령으로 쓰지 않도록 바꿨다

최종 대응은 배치·배선 검토와 입력 처리였다. 수신기를 금속 구조물·전력 배선에서 떨어뜨리고 신호선과 GND 귀환선을 가까이 배치하는 방향을 검토했다. 소프트웨어에서는 잡음의 성격에 따라 서로 다른 처리를 넣었다.

| 최종 코드의 처리 | 실제 설정 | 제어 경로에서의 역할 |
| --- | --- | --- |
| throttle·steering 저역통과 필터 | `alpha=0.4` | 짧은 입력 변화가 이동·조향 요구에 바로 반영되는 정도를 완화 |
| engage 저역통과 필터 | `alpha=0.02` | 활성화 신호에 더 강한 평활화 적용 |
| 중립 데드밴드 | 중심에서 편차가 `50 us` 미만이면 0 처리 | 작은 중립 편차를 주행 의도로 해석하지 않음 |
| 활성화 지속성 검사 | 50 ms 주기의 상태 갱신에서 카운터 사용 | 한 번의 판정만으로 활성 상태가 바뀌는 것을 완화 |

필터는 다음과 같이 구현되어 있다.

```cpp
filtered_throttle_pwm = kAlpha_1 * throttle_pwm + (1.0 - kAlpha_1) * filtered_throttle_pwm;
```

throttle과 steering에는 같은 계수를 사용하지만 engage는 더 작은 계수를 사용한다. 조작 응답과 활성화 판단이 요구하는 반응 특성을 구분한 것이다.

지속성 카운터는 판정에 따라 증가·감소하고 `-3~3`으로 제한되며, 0보다 크면 engage 상태로 판단한다. 따라서 “항상 정확히 3회 연속 입력을 받아야 켜진다”는 단순 규칙으로 설명할 수는 없다.

중립값도 무조건 1500 us로 가정하지 않았다. 데드밴드 기준은 throttle 1488 us, steering 1492 us이다. 다만 throttle 정규화식에는 1491 us가 남아 있어 기준이 완전히 통일되어 있지는 않다.

## 바뀐 것은 필터 하나가 아니라 입력에 대한 신뢰 기준이었다

이 작업에서 중요한 구분은 **수신기 값이 존재하는 것**과 **실제 조작 의도로 받아들여도 되는 것**이었다. 중립 부근의 편차, 순간적인 튐, 활성화 신호는 같은 방식으로 처리할 수 없었다.

이를 각각 필터·데드밴드·지속성 검사로 다룬 과정은 입력 신호를 제어기 앞단에서 정제하는 설계로 이어졌다. 금속과 포일에 따른 변화는 하드웨어 조건을 조사할 이유를 주었고, 코드 변경은 남아 있는 입력 변동의 영향을 줄이는 수단이었다.

## 관련 코드와 기록

- [receiver_pwm_test.ino](../../../../firmware/testers/receiver_pwm_test/receiver_pwm_test.ino): 펄스폭 측정 방식과 출력 항목.
- [physical_balance_controller.ino](../../../../firmware/physical_balance_controller/physical_balance_controller.ino): `kAlpha_1`, `kAlpha_2`, 데드밴드, engage 카운터.
- [개발 과정](../../development-process.md): 수신기와 배선 조사 배경.

최종 구현은 코드로 확인할 수 있다. 금속·포일 실험 결과는 기존 작업 기록의 관찰이며, 공개된 원시 로그와 전후 스파이크 발생률은 없다. 따라서 “입력 처리와 배치 검토로 대응했다”까지 설명하고, 노이즈가 몇 퍼센트 감소했다고 말하지 않는다.

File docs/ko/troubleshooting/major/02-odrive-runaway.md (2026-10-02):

# 모터가 갑자기 가속했다: ODrive 경로를 나누어 조사하기

[English](../../../troubleshooting/major/02-odrive-runaway.md) | [전체 트러블슈팅](../../troubleshooting.md)

> 간헐적인 비정상 가속을 RC·홀센서·명령 전달·모터 제어 경로로 나누어 조사했다. 기존 기록에서는 펌웨어 다운그레이드 이후 증상이 사라졌다고 보고하며, 저장소에는 각 경로를 확인하는 테스터와 최종 상태·전류 제한 코드가 남아 있다.

## 같은 바퀴 움직임이라도 RC 노이즈와는 구분해야 했다

ODrive를 통한 구동 중 갑자기 가속하거나 정상적으로 멈추지 않는 현상이 있었다. RC 신호 튐도 존재했지만, 그것만으로 모든 비정상 동작을 설명할 수는 없었다. 자세 제어, 입력 해석, 홀센서 상태, ODrive 설정이 동시에 개입하는 전체 로봇에서 곧바로 게인을 바꾸면 원인 후보가 더 섞인다.

따라서 조사 질문을 “로봇이 왜 폭주하는가”에서 **“어느 경로까지는 정상이라고 확인할 수 있는가”**로 바꿨다.

## 전체 로봇을 네 가지 확인 경로로 나눴다

저장소의 테스터는 각기 다른 변수를 남기고 나머지 경로를 덜어낸다.

| 확인 경로 | 확인 가능한 항목 | 분리하려는 원인 후보 |
| --- | --- | --- |
| 홀센서 단독 | A/B/C 상태, 전이 횟수, illegal 상태 카운터 | 센서 연결·상태 신호 문제 |
| 수신기 단독 | throttle·steering·engage 펄스폭 | RC 입력 자체의 문제 |
| 수신기–ODrive 통합 | PWM, 좌우 전류 요청, active 상태 | 입력을 전류로 변환하는 경로 |
| 전류 명령 단독 | axis별 전류 요청, 정지·IDLE 요청 | RC·IMU를 제외한 모터 명령 경로 |

홀센서 테스터는 A0/A1/A2를 읽고, 세 신호의 합이 0 또는 3인 상태를 illegal로 분류한다. 출력에는 다음 항목이 있다.

```text
hall_a    hall_b    hall_c    state    transitions    illegal
```

이 카운터는 상태 이상을 볼 수 있는 수단이지 “실험에서 illegal이 0회였다”는 결과표가 아니다. 기존 기록에서는 홀센서 확인만으로 폭주 원인이 드러나지 않아 다른 경로 조사를 계속했다고 설명한다.

## 입력을 제거한 시험이 판단을 좁혀주었다

[전류 명령 테스터](../../../../firmware/testers/motor_current_test/motor_current_test.ino)는 RC와 IMU를 사용하지 않는다. Arduino 시리얼 명령으로 한 축 또는 양쪽 축에 전류를 요청하고, 0 A 요청과 IDLE 전환을 구분한다.

| 테스터 명령 | 코드에서 하는 일 |
| --- | --- |
| `m <axis> <amps>` | 지정 축에 제한된 전류 요청 |
| `b <amps>` | 양쪽 축에 전류 요청 |
| `s` | 양쪽 전류를 0 A로 요청 |
| `d` | 0 A 요청 후 양쪽 축에 IDLE 요청 |

이 구조 덕분에 “수신기 입력이 잘못되었는가”와 “정상적인 전류 요청에도 모터 경로가 비정상적인가”를 다른 시험으로 다룰 수 있었다. 저장소는 원래 프로젝트 자료를 복원·정리한 형태이므로, 현재 테스터의 존재만으로 당시 모든 시험의 수치 결과까지 복원되었다고 보지는 않는다.

기존 조사 기록의 결과는 **펌웨어 다운그레이드 이후 폭주 증상이 사라졌다**는 것이다. 이 결과는 ODrive 펌웨어·홀센서 구동 호환성 경로를 의심할 이유를 주었다. 다만 정확한 변경 전후 버전표와 내부 결함 추적 기록이 없어, 특정 버그를 완전히 규명했다고 결론내리지는 않았다.

## 증상 해소 뒤에도 모터 상태를 명시적으로 다뤘다

최종 코드에는 구동 상태를 전환하는 `EngageMotors()`와 전류 명령을 제한하는 `ApplyMotorCommands()`가 있다.

```cpp
float current_command_0 = constrain(torque_input_0, -kMaxAbsCurrent, kMaxAbsCurrent);
float current_command_1 = constrain(torque_input_1, -kMaxAbsCurrent, kMaxAbsCurrent);
```

`kMaxAbsCurrent=8.0`이므로 Arduino가 보내는 전류 요청은 ±8 A로 제한한다. engage 신호와 기울기 조건은 ODrive 축의 `IDLE ↔ CLOSED_LOOP_CONTROL` 전환 요청에 사용한다.

여기서 0 A 요청, 축의 IDLE 요청, 전원 차단은 서로 다른 동작이다. 이 코드가 보장하는 것은 요청값 제한과 상태 전환 로직의 존재이며, 실제 전류 측정이나 모든 ODrive 내부 고장에 대한 독립 보호를 뜻하지 않는다.

## 해결 결과와 원인 규명을 구분하게 되었다

이번 문제는 펌웨어 변경이 증상에 영향을 주었다는 경험적 결과를 남겼다. 동시에 RC·홀센서·직접 전류 경로를 나누면 다음 조사에서 같은 현상을 더 좁은 범위로 재현할 수 있다는 방법도 남겼다.

## 관련 코드와 기록

- [hall_sensor_test.ino](../../../../firmware/testers/hall_sensor_test/hall_sensor_test.ino): 상태·전이·illegal 카운터.
- [receiver_pwm_test.ino](../../../../firmware/testers/receiver_pwm_test/receiver_pwm_test.ino): 입력 펄스폭 관찰.
- [odrive_receiver_test.ino](../../../../firmware/testers/odrive_receiver_test/odrive_receiver_test.ino): PWM과 전류 요청의 연결.
- [motor_current_test.ino](../../../../firmware/testers/motor_current_test/motor_current_test.ino): RC·IMU 없이 전류·상태 요청.
- [최종 제어기](../../../../firmware/physical_balance_controller/physical_balance_controller.ino): 전류 제한과 상태 전환.

다운그레이드 후 증상 소멸은 기존 기록에 근거한다. 정확한 버전 조합, 동일 조건의 반복 횟수, ODrive 오류 상태 로그가 추가되면 펌웨어 변경과 결과의 연결을 더 강하게 검증할 수 있다.

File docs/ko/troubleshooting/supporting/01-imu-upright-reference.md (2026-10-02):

# IMU의 0°가 로봇의 직립점은 아니었다

[English](../../../troubleshooting/supporting/01-imu-upright-reference.md) | [전체 트러블슈팅](../../troubleshooting.md)

> 센서 캘리브레이션과 기구의 직립 기준을 구분하고, 최종 자세 계산에 오프셋을 적용했다.

## 계속 보정하는 현상을 게인만으로 다룰 수 없는 이유

IMU가 보고하는 각도와 실제 몸체의 직립 자세가 다르면 제어기는 잘못된 기준점을 향해 계속 복원하려 한다. 기존 작업 기록에서 캘리브레이션과 기준점 관리를 다룬 이유다. 이 현상은 게인을 바꾸기 전에 센서 시작 상태·장착 방향·직립 기준을 함께 확인해야 하는 문제였다.

## 센서 상태와 직립 기준을 따로 확인하도록 구성했다

BNO055 초기화 실패 시 실행을 멈추고, 캘리브레이션 상태를 확인하는 함수와 EEPROM 저장·복원 함수를 준비했다. 이와 별도로 실제 자세 계산에 `imu_angle_offset`을 두었다.

| 코드 경로 | 확인하거나 바꾸는 것 |
| --- | --- |
| `bno.begin()` | 센서가 초기화되는지 확인 |
| `checkIMUCalibration()` | system·gyro·accel·mag 보정 상태 출력 |
| `saveCalibration()` / `loadCalibration()` | 22바이트 보정 데이터 저장·복원 |
| `SetImuAngleOffset()` | 제어에 사용하는 직립 기준 조정 |

센서 보정 데이터와 몸체 직립 오프셋은 같은 값이 아니다. 센서를 보정해도 장착 각도와 기구의 평형점 차이는 별도로 남을 수 있기 때문이다.

## 최종 코드에서 실제로 적용되는 것은 무엇인가

```cpp
float imu_angle_offset = 3.5;
```

자세 계산은 다음과 같다.

```cpp
theta = imu_enabled * (euler_angles.y() + imu_angle_offset);
```

이 식에서 보정 후 0°는 원시 y각이 -3.5°인 지점이다. **이는 코드에서 계산한 기준의 의미이며 실측 자세 로그가 아니다.** 기울기 임계값 검사에도 같은 오프셋을 더한다.

한편 `setup()`의 `loadCalibration()`과 `checkIMUCalibration()` 호출은 주석 처리되어 있다. 저장·복원 함수가 남아 있어도 현재 스케치가 부팅마다 자동 복원과 상태 출력을 수행하는 것은 아니다.

## 기준점을 제어기의 입력 조건으로 다루게 되었다

여기서 남은 설계 판단은 캘리브레이션 상태와 실제 직립점을 분리한 것이다. 오프셋은 시리얼 명령 `r`에 연결되어 자세 게인과 별도로 바꿀 수 있다. 따라서 “복원력이 약한가”와 “복원하려는 기준점이 다른가”를 다른 변수로 조사할 수 있다.

## 관련 코드와 기록

[최종 제어기](../../../../firmware/physical_balance_controller/physical_balance_controller.ino)의 `setup()`, `checkIMUCalibration()`, `SetImuAngleOffset()`, `BalanceController()`를 연결해 확인할 수 있다. 오프셋 구현은 코드로 검증되지만, 현재 공개 자료에는 동일 자세에서 재부팅 전후 각도를 비교한 로그가 없어 재시작 재현성 개선량까지 입증하지는 않는다.

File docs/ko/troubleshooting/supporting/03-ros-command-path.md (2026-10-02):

# Navigation 명령을 그대로 보내지 않고 밸런스 제어기를 통과시켰다

[English](../../../troubleshooting/supporting/03-ros-command-path.md) | [전체 트러블슈팅](../../troubleshooting.md)

> `move_base` 출력은 이동 의도로 받고, IMU·Odom을 사용하는 밸런스 제어기가 최종 `/cmd_vel`을 출력하도록 시뮬레이션 경로를 구성했다.

## 이동 요청과 자세 복원이 같은 출력 경로를 사용한다

Navigation은 목적지로 가기 위한 이동 속도를 요청한다. 하지만 2륜 밸런스 로봇의 바퀴는 이동과 몸체 복원을 동시에 수행한다. 따라서 상위 속도 명령을 베이스에 직접 전달하면 자세 제어가 계산해야 할 출력과 충돌할 수 있었다.

이 항목은 독립적인 고장 로그보다, 시뮬레이션에서 명령 책임을 나눈 설계 문제에 해당한다.

## 먼저 Navigation의 출력 목적지를 바꿨다

[move_base.launch](../../../../ros_ws/src/navigation/launch/move_base.launch)는 목적지 토픽의 기본값을 `/before_vel`로 두고 출력 remap을 적용한다.

```xml
<arg name="cmd_vel_topic" default="/before_vel" />
```

```xml
<remap from="cmd_vel" to="$(arg cmd_vel_topic)"/>
```

Navigation이 계산한 명령은 `/before_vel`에 도착한다. 이 토픽은 바퀴에 바로 전달할 최종 출력이 아니라 밸런스 제어기에 주는 목표 속도·회전 입력이다.

## 밸런스 제어기에서 어떤 정보가 추가되는가

[LiDAR 시뮬레이션 제어기](../../../../ros_ws/src/balance_robot_control/src/controllers/pid_control_before_vel_lidar.py)는 입력과 상태를 다음과 같이 나눈다.

| 입력·출력 | 코드에서의 역할 |
| --- | --- |
| `/before_vel` | 목표 선속도·회전 입력 설정 |
| `/odom` | 현재 선속도 갱신 |
| `/imu` | pitch·자세 변화 계산, 제어 출력 갱신 |
| `/cmd_vel` | 계산된 베이스 명령 발행 |

속도 오차를 목표 기울기로 변환하고 현재 pitch와 비교한다.

```python
speed_error = self.setpoint_speed - self.current_speed
self.setpoint_angle = self.Kp_speed * speed_error
angle_error = self.setpoint_angle - current_pitch_angle
output_angle = (self.Kp_angle * angle_error + self.Kd_angle * pitch_rate)
```

이 과정을 통해 상위 명령에 현재 이동·자세 상태가 반영된다. LiDAR 버전의 제어 출력 계산은 IMU 콜백에서 실행된다. 따라서 `rospy.Rate(200)` 선언만으로 전체 제어가 측정된 200 Hz라고 결론내리지는 않는다.

## 토픽 이름보다 실제 발행·구독 관계가 중요했다

문서상의 경로는 `move_base → /before_vel → balance_robot_control → /cmd_vel`이다. launch remap과 제어기의 subscriber·publisher를 함께 읽어야 이 관계를 확인할 수 있다.

시뮬레이션 Navigation 화면

*공개된 depth 모델 시뮬레이션 화면. 위 코드 발췌는 LiDAR 버전이며, 영상·이미지는 depth 버전의 워크플로 결과다.*

두 모델의 설정이 완전히 같다는 의미는 아니지만, 상위 이동 의도와 최종 밸런스 출력을 구분하는 구조를 공유한다. 실물 쪽에서는 Arduino가 ODrive 전류 요청을 계산한다. 구조의 공통점과 실물 자율주행 완료 여부는 별개의 사실이다.

## 관련 코드와 기록

- [move_base.launch](../../../../ros_ws/src/navigation/launch/move_base.launch): Navigation 출력 remap.
- [LiDAR 제어 코드](../../../../ros_ws/src/balance_robot_control/src/controllers/pid_control_before_vel_lidar.py): 입력·피드백·최종 출력 연결.
- [제어 패키지 설명](../../../../ros_ws/src/balance_robot_control/README.md): 모델별 구조와 튜닝 경로.
- [시뮬레이션 영상](../../../../media/process/simulation_depth_navigation_demo.webm): depth 워크플로 동작.
- [Sim2Real 범위](../../sim2real.md): 실물 자율주행은 연동 실험 단계.

launch와 코드로 경로를 검토할 수 있고, 실행 중에는 `rostopic info /before_vel`, `rostopic info /cmd_vel`로 실제 publisher·subscriber를 확인할 수 있다. 공개 데모는 시뮬레이션 결과이며 실물의 완성된 자율주행 증거로 사용하지 않는다.

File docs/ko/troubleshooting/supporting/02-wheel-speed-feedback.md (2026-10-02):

# 속도 값이 튀면 모터 보정도 튄다: 피드백 처리의 변화

[English](../../../troubleshooting/supporting/02-wheel-speed-feedback.md) | [전체 트러블슈팅](../../troubleshooting.md)

> 과거 코드에서는 최근 값과 중앙값으로 급변 샘플을 처리했고, 최종 코드에서는 수신·파싱과 속도 보정 제한을 사용한다. 과거 실험과 현재 활성 처리를 구분해 읽을 수 있다.

## 속도 피드백의 이상이 자세 제어까지 영향을 주는 경로

속도 루프는 목표 속도에서 좌우 바퀴 평균 속도를 빼 보정값을 계산한다. 이 값은 두 모터에 공통으로 들어간다. 따라서 속도 샘플 하나가 비정상적으로 변해도 조작 입력이 바뀐 것처럼 보정값이 달라질 수 있다.

이 문제는 바퀴 속도를 출력해 보기만 하는 문제가 아니라 **어떤 샘플을 제어에 사용할 것인가**의 문제였다.

## 과거 코드에서는 최근 샘플과 비교했다

[legacy 제어기](../../../../archive/arduino_firmware/legacy_balance_controller.ino)에는 최근 5개 값의 절댓값 평균을 이용하는 임계값 함수가 있다.

```cpp
return 3.0 * (sum / N);
```

새 값과 직전 값의 차이가 이 임계값을 넘으면 이전 두 값과 새 값의 중앙값을 사용한다.

```cpp
if (abs(phi_dot_counts_0 - prev_dot_0) > adaptive_threshold_dot_0) {
    phi_dot_counts_0 = median_phi_dot_0;
}
```

즉 단일 고정 한계만 비교하기보다 최근 값의 크기를 반영하고, 급변 샘플의 영향을 중앙값으로 줄이는 방식을 실험했다. 다만 임계값 계산 이력에도 새 값이 들어가므로 이를 검증된 통계적 이상치 판별기라고 확대해 설명하지 않는다.

## 최종 코드를 보면 남은 처리와 빠진 처리가 보인다

| 경로 | 과거 코드 | 최종 코드 |
| --- | --- | --- |
| 급변 값 처리 | 최근 이력 임계값과 3개 값 중앙값 | 동일한 경로는 활성 루프에 없음 |
| 수신 처리 | 위치·속도 값 확인 경로 | 읽기 전후 현재 수신 바이트 비우기, `parseFloat()` 2회 |
| 속도 평활화 | 과거 처리식과 계수 사용 | 평활화 식은 있으나 `kAlpha_3=1` |
| 제어 영향 제한 | 과거 제어 설정 | 속도 적분 ±5, 보정 출력 ±6 |

최종 코드의 평활화 식에 현재 계수를 넣으면 새 값이 그대로 통과한다. 변수명이 `filtered_phi_dot`여도 이 설정에서는 속도 평활화가 작동하지 않는다.

또한 최종 파일에 `filterEncoderData()`라는 보조 함수가 남아 있지만 활성 `BalanceController()`에서 호출하지 않는다. 함수 존재와 실제 제어 경로 적용은 구분해야 한다. 수신 버퍼 정리도 응답의 길이·샘플 유효성·타임아웃을 검증하는 완전한 프레임 파서는 아니다.

## 피드백 품질과 출력 제한을 별개로 보게 되었다

적분과 출력 제한은 비정상 샘플이 만든 보정의 크기를 제한한다. 반면 이상치 판별은 입력 샘플 자체를 판단한다. 두 방식은 역할이 다르며, 어느 하나가 있다고 다른 하나를 수행한다고 볼 수 없다.

과거·최종 코드를 나란히 비교하면 이상치 처리 실험은 확인할 수 있지만, 그 실험이 최종 코드에 전부 적용되었다는 설명은 맞지 않는다.

## 관련 코드와 기록

- [legacy_balance_controller.ino](../../../../archive/arduino_firmware/legacy_balance_controller.ino): `updateThreshold()`, `getMedian()`, 급변 값 대체.
- [최종 제어기](../../../../firmware/physical_balance_controller/physical_balance_controller.ino): 수신·파싱, `kAlpha_3`, 속도 보정 제한.

공개 코드로 처리 방식의 변화를 확인할 수 있다. 원시 시리얼 응답과 속도·전류 요청을 함께 기록한 전후 로그는 없어, 필터 적용에 따른 진동 감소량까지 제시하지 않는다.

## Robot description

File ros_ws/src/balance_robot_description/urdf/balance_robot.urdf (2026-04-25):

<?xml version="1.0" ?>
<!-- =================================================================================== -->
<!-- |    This document was autogenerated by xacro from robot_new.xacro                | -->
<!-- |    EDITING THIS FILE BY HAND IS NOT RECOMMENDED                                 | -->
<!-- =================================================================================== -->
<robot name="balancing">
  <link name="base_link">
    <inertial>
      <mass value="0.2"/>
      <origin xyz="0 0 0"/>
      <inertia ixx="0.0010416666666666667" ixy="0.0" ixz="0.0" iyy="0.0006933333333333335" iyz="0.0" izz="0.0004016666666666667"/>
    </inertial>
    <visual>
      <origin xyz="0 0 0"/>
      <geometry>
        <box size="0.04 0.15 0.2"/>
      </geometry>
    </visual>
	<collision>
      <origin xyz="0 0 0"/>
      <geometry>
        <box size="0.04 0.15 0.2"/>
		</geometry> 
	</collision>
  </link>
  <gazebo reference="base_link">
    <mu1>0.7</mu1>
    <mu2>0.7</mu2>
    <kp>10000</kp>
    <kd>10000</kd>
    <material>Gazebo/White</material>
  </gazebo>
  <joint name="motor_dx_joint" type="fixed">
    <origin rpy="0 0 0" xyz="0 0.04 -0.1125"/>
    <parent link="base_link"/>
    <child link="motor_dx_link"/>
  </joint>
  <link name="motor_dx_link">
    <inertial>
      <mass value="0.1"/>
      <origin rpy="1.57075 0 0" xyz="0 0 0"/>
      <inertia ixx="4.604166666666667e-05" ixy="0.0" ixz="0.0" iyy="4.604166666666667e-05" iyz="0.0" izz="7.812500000000002e-06"/>
    </inertial>
    <visual>
      <origin rpy="1.57075 0 0" xyz="0 0 0"/>
      <geometry>
        <cylinder length="0.07" radius="0.0125"/>
      </geometry>
    </visual>
    <collision>
      <origin rpy="1.57075 0 0" xyz="0 0 0"/>
      <geometry>
        <cylinder length="0.07" radius="0.0125"/>
      </geometry>
    </collision>
  </link>
  <gazebo reference="motor_dx_link">
    <mu1>0.7</mu1>
    <mu2>0.7</mu2>
    <kp>10000</kp>
    <kd>10000</kd>
    <material>Gazebo/Gray</material>
  </gazebo>
  <joint name="wheel_dx_joint" type="continuous">
    <origin rpy="0 0 0" xyz="0 0.05 0"/>
    <parent link="motor_dx_link"/>
    <child link="wheel_dx_link"/>
    <axis xyz="0 1 0"/>
  </joint>
  <link name="wheel_dx_link">
    <inertial>
      <mass value="0.05"/>
      <origin rpy="1.57075 0 0" xyz="0 0 0"/>
      <inertia ixx="2.0641666666666666e-05" ixy="0.0" ixz="0.0" iyy="2.0641666666666666e-05" iyz="0.0" izz="2.6406250000000005e-05"/>
    </inertial>
    <visual>
      <origin rpy="1.57075 0 0" xyz="0 0 0"/>
      <geometry>
        <cylinder length="0.027" radius="0.0325"/>
      </geometry>
    </visual>
    <collision>
      <origin rpy="1.57075 0 0" xyz="0 0 0"/>
      <geometry>
        <cylinder length="0.027" radius="0.0325"/>
      </geometry>
    </collision>
  </link>
  <gazebo reference="wheel_dx_link">
    <mu1>0.7</mu1>
    <mu2>0.7</mu2>
    <kp>10000</kp>
    <kd>10000</kd>
    <material>Gazebo/Black</material>
  </gazebo>
  <joint name="motor_sx_joint" type="fixed">
    <origin rpy="0 0 0" xyz="0 -0.04 -0.1125"/>
    <parent link="base_link"/>
    <child link="motor_sx_link"/>
  </joint>
  <link name="motor_sx_link">
    <inertial>
      <mass value="0.1"/>
      <origin rpy="1.57075 0 0" xyz="0 0 0"/>
      <inertia ixx="4.604166666666667e-05" ixy="0.0" ixz="0.0" iyy="4.604166666666667e-05" iyz="0.0" izz="7.812500000000002e-06"/>
    </inertial>
    <visual>
      <origin rpy="1.57075 0 0" xyz="0 0 0"/>
      <geometry>
        <cylinder length="0.07" radius="0.0125"/>
      </geometry>
    </visual>
    <collision>
      <origin rpy="1.57075 0 0" xyz="0 0 0"/>
      <geometry>
        <cylinder length="0.07" radius="0.0125"/>
      </geometry>
    </collision>
  </link>
  <gazebo reference="motor_sx_link">
    <mu1>0.7</mu1>
    <mu2>0.7</mu2>
    <kp>10000</kp>
    <kd>10000</kd>
    <material>Gazebo/Gray</material>
  </gazebo>
  <joint name="wheel_sx_joint" type="continuous">
    <origin rpy="0 0 0" xyz="0 -0.05 0"/>
    <parent link="motor_sx_link"/>
    <child link="wheel_sx_link"/>
    <axis xyz="0 1 0"/>
  </joint>
  <link name="wheel_sx_link">
    <inertial>
      <mass value="0.05"/>
      <origin rpy="1.57075 0 0" xyz="0 0 0"/>
      <inertia ixx="2.0641666666666666e-05" ixy="0.0" ixz="0.0" iyy="2.0641666666666666e-05" iyz="0.0" izz="2.6406250000000005e-05"/>
    </inertial>
    <visual>
      <origin rpy="1.57075 0 0" xyz="0 0 0"/>
      <geometry>
        <cylinder length="0.027" radius="0.0325"/>
      </geometry>
    </visual>
    <collision>
      <origin rpy="1.57075 0 0" xyz="0 0 0"/>
      <geometry>
        <cylinder length="0.027" radius="0.0325"/>
      </geometry>
    </collision>
  </link>
  <gazebo reference="wheel_sx_link">
    <mu1>0.7</mu1>
    <mu2>0.7</mu2>
    <kp>10000</kp>
    <kd>10000</kd>
    <material>Gazebo/Black</material>
  </gazebo>
  <link name="battery_link">
    <inertial>
      <mass value="0.15"/>
      <origin xyz="0 0 0.0"/>
      <inertia ixx="0.00011249999999999998" ixy="0.0" ixz="0.0" iyy="3.125e-05" iyz="0.0" izz="0.00012124999999999999"/>
    </inertial>
    <visual>
      <origin xyz="0 0 0"/>
      <geometry>
        <box size="0.04 0.09 0.03"/>
      </geometry>
    </visual>
    <collision>
      <origin xyz="0 0 0"/>
      <geometry>
        <box size="0.04 0.09 0.03"/>
      </geometry>
    </collision>
  </link>
  <gazebo reference="battery_link">
    <mu1>0.3</mu1>
    <mu2>0.3</mu2>
    <kp>10000</kp>
    <kd>10000</kd>
    <material>Gazebo/Green</material>
  </gazebo>
  <joint name="battery_joint" type="fixed">
    <origin rpy="0 0 0" xyz="0 0 0.115"/>
    <parent link="base_link"/>
    <child link="battery_link"/>
  </joint>
  <!--  SENSORS -->
  
  <!-- DIFFERENTIAL DRIVE -->
  
  <gazebo>
    <plugin filename="libgazebo_ros_diff_drive.so" name="differential_drive_controller">
      <legacyMode>false</legacyMode>
	    <alwaysOn>false</alwaysOn>
	    <max_velocity>100</max_velocity>
      <updateRate>200</updateRate>
      <leftJoint>wheel_dx_joint</leftJoint>
      <rightJoint>wheel_sx_joint</rightJoint>
      <wheelSeparation>0.2</wheelSeparation>
      <wheelDiameter>0.065</wheelDiameter>
      <torque>100</torque>
      <commandTopic>/cmd_vel</commandTopic>
      <odometryTopic>odom</odometryTopic>
      <odometryFrame>odom</odometryFrame>
      <odometrySource>2</odometrySource>
      <publishTf>false</publishTf>
      
      <param name="odometrySource" type="int" value="2"/>
      <robotBaseFrame>base_link</robotBaseFrame>
      <wheelTorque>100</wheelTorque>
      <wheelAcceleration>4</wheelAcceleration>
      <publishWheelJointState>true</publishWheelJointState>
      <publishOdomTF>true</publishOdomTF>
      <publishWheelTF>true</publishWheelTF>
      <rosDebugLevel>debug</rosDebugLevel>
    </plugin>
  </gazebo>
</robot>

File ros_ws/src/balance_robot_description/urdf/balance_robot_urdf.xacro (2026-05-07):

<?xml version="1.0"?>

<robot name="balance_robot" xmlns:xacro="http://ros.org/wiki/xacro">
  <xacro:arg name="use_actual_stl_assembly" default="false"/>
  <xacro:property name="stl_assembly_origin_xyz" value="-0.110383 -0.202 0.064314"/>
  <xacro:property name="stl_assembly_origin_rpy" value="0 0 0"/>
  <xacro:property name="stl_assembly_scale" value="0.001 0.001 0.001"/>

  <xacro:include filename="$(find robot_description)/urdf/color_properties.xacro"/>
  <xacro:include filename="$(find robot_description)/urdf/balance_robot_gazebo.xacro"/>

  <link name="base_footprint"/>

  <joint name="base_joint" type="fixed">	
    <parent link="base_footprint"/>
    <child link="base_link"/>
    <origin xyz="0.0 0.0 0.0" rpy="0 0 0"/>
  </joint>

  <link name="base_link">
    <xacro:if value="$(arg use_actual_stl_assembly)">
      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
    </xacro:if>

    <xacro:unless value="$(arg use_actual_stl_assembly)">
      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
    </xacro:unless>

    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

    <inertial>
      <origin xyz="0 0 0.31" rpy="0 0 0"/>
      <mass value="11.0"/>
      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
    </inertial>
  </link>

  <joint name="wheel_left_joint" type="continuous">
    <parent link="base_link"/>
    <child link="wheel_left_link"/>
    <origin xyz="0.0 0.215 0.085" rpy="1.57 0 0"/>
    <axis xyz="0 0 1"/>
  </joint>

  <link name="wheel_left_link">
    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

    <inertial>
      <origin xyz="0 0 0" />
      <mass value="3" />
      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
      </inertial>
  </link>

  <joint name="wheel_right_joint" type="continuous">
    <parent link="base_link"/>
    <child link="wheel_right_link"/>
    <origin xyz="0.0 -0.215 0.085" rpy="1.57 0 0"/>
    <axis xyz="0 0 1"/>
  </joint>

  <link name="wheel_right_link">
    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

    <inertial>
      <origin xyz="0 0 0" />
      <mass value="3" />
      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
      </inertial>
  </link>
  
  <joint name="imu_joint" type="fixed">
    <parent link="base_link"/>
    <child link="imu_link"/>
    <origin xyz="0 0 0.535" rpy="0 0 0"/>
  </joint>

  <link name="imu_link"/>

  <joint name="scan_joint" type="fixed">
    <parent link="base_link"/>
    <child link="base_scan"/>
    <origin xyz="0.0 0.0 0.565" rpy="0 0 0"/>
  </joint>

  <link name="base_scan">
    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

    <inertial>
      <mass value="0.114" />
      <origin xyz="0 0 0" />
      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
    </inertial>
  </link>
</robot>

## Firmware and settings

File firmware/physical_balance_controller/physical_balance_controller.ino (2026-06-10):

// Arduino sketch for a two-wheeled self-balancing robot using a layered balance controller
// with BNO055 IMU module and ODrive motor controller. Tested on Arduino Mega 2560 with ODrive 3.6.

#include <Wire.h>
#include <Metro.h>
#include <Servo.h>
#include <Adafruit_Sensor.h>
#include <Adafruit_BNO055.h>
#include <utility/imumaths.h>
#include <ODriveArduino.h>
#include <Command_processor.h>
#include <EEPROM.h>

namespace {
// Hardware settings.
constexpr unsigned short kLedPin = 13;
constexpr unsigned short kSteeringPwmInputPin = 2;
constexpr unsigned short kThrottlePwmInputPin = 3;
constexpr unsigned short kEngagePwmInputPin = 19;

constexpr unsigned long kSerialBaudratePc = 115200;
constexpr unsigned long kSerialBaudrateOdrive = 115200;
constexpr int kMotorDir0 = 1; // Can only be 1 or -1.
constexpr int kMotorDir1 = -1; // Can only be 1 or -1.
constexpr int kSteeringPolarity = 1; // Can only be 1 or -1.
constexpr int kThrottlePolarity = 1; // Can only be 1 or -1.

// RC settings.
constexpr int kSteeringPwmOffset = 1492;
constexpr int kThrottlePwmOffset = 1488;
constexpr int kEngageThresholdPwm = 1500;
constexpr int kControlThreshold = 50; // Steering or throttle threshold to disable wheel angle correction

// Balance, speed, and steering control gains.
float K_theta = 24;
float Ki = 0;
float K_theta_dot = 1.7;
float imu_angle_offset = 3.5;  // IMU 각도 오프셋 값
float adjustment_value = 0;  // 원하는 값으로 설정
float scaling_factor = 10000;
constexpr float kIntegralMax = 100.0;
float kpThrottle = 0.003;
float kpSteer = 0.001;
float kdSteer = 0.008; 
float theta = 0;
float kpspeed = 1.2;  // P 게인 속도 0.3
float kispeed = 0.1; // I 게인 속도 0.08
float kdspeed = 7;  // D 게인 속도
float kIntegralspeedMax = 5;  // I 최대값
constexpr float controlspeed = 6.0; // 최대 컨트롤 출력
constexpr float maxspeed = 1.5;   // 앞뒤 속도
constexpr float maxSpeedDiff = 0.7; // 좌우 속도차이
float integral_error = 0.0;
static float prev_speed_error = 0.0;
static float integral_speed_error = 0.0;
static float derivative_speed_error = 0.0;

constexpr float kWheelRadius = 0.0825;
float phi_dot_counts_0 = 0.0;
float phi_dot_counts_1 = 0.0;
float filtered_phi_dot_0 = 0.0;
float filtered_phi_dot_1 = 0.0;

constexpr float kAlpha_1 = 0.4;  // 필터 강도 (0.0 ~ 1.0 사이, 낮을수록 더 부드러움)
constexpr float kAlpha_2 = 0.02;
constexpr float kAlpha_3 = 1;
float filtered_throttle_pwm = 0;
float filtered_steering_pwm = 0;
float filtered_engage_pwm = 1000;
constexpr uint8_t kTiltDisengageThresholdDegrees = 30; // 전원이 차단되는 각도 임계값
constexpr float kMaxAbsCurrent = 8.0;
// Final motor current request variables.
float torque_input_0 = 0.0;
float torque_input_1 = 0.0;

// Task scheduling settings.
constexpr unsigned int kBlinkIntervalMs = 200;
constexpr unsigned int kControllerIntervalMs = 0;
constexpr unsigned int kActivationIntervalMs = 50;
constexpr unsigned int kPrintIntervalMs = 50;

unsigned long loop_start_time;
unsigned long loop_duration;

// State variables.
bool motors_active = false;
bool tilt_limit_exceeded = false;
int engage_signal_persistence = 0;
bool engage = false;

// PWM decoder variables.
unsigned long last_throttle_pwm_rise_time = 0;
unsigned long last_steering_pwm_rise_time = 0;
unsigned long last_engage_pwm_rise_time = 0;
int throttle_pwm = 0;
int steering_pwm = 0;
int engage_pwm = 0;

bool was_driving = false;
bool initialized = false;
    // === 추가할 변수 ===
int drive_signal_persistence = 0;  // 주행 상태 필터링 변수
constexpr int kPersistenceThreshold = 3;  // 신호 지속성 임계값 (3번 이상 유지될 때만 동작)

// Interactive flags
bool imu_enabled = true;
bool rc_enabled = true;
bool rc_print_enabled = false;
bool motion_controller_enabled = true;

Adafruit_BNO055 bno = Adafruit_BNO055();
ODriveArduino odrive(Serial3);

// Instantiate Metros for task scheduling.
Metro led_metro = Metro(kBlinkIntervalMs);
Metro controller_metro = Metro(kControllerIntervalMs);
Metro activation_metro = Metro(kActivationIntervalMs);
Metro print_metro = Metro(kPrintIntervalMs);
Command_processor cmd;
}

#define HISTORY_SIZE 3  // 최근 저장할 데이터 개수

float encoder_history_0[HISTORY_SIZE] = {0};  // 모터 0 속도 기록
float encoder_history_1[HISTORY_SIZE] = {0};  // 모터 1 속도 기록
int history_index = 0;  // 순환 버퍼 인덱스

float filterEncoderData(float new_value, float *history) {
    float prev_value = history[(history_index - 1 + HISTORY_SIZE) % HISTORY_SIZE];  // 직전 값

    // ✅ 값이 100 초과하면 이전 값 반환
    if (abs(new_value) > 100) {
        // Serial.println("⚠️ 이상치 감지! 이전 값 유지");
        return prev_value;
    }

    // ✅ 정상적인 값이면 저장 후 반환
    history[history_index] = new_value;
    history_index = (history_index + 1) % HISTORY_SIZE;

    return new_value;
}

void saveCalibration() {
    uint8_t calibrationData[22]; 
    bno.getSensorOffsets(calibrationData);
    Serial.println("Saving calibration...");

    for (int i = 0; i < 22; i++) {
        EEPROM.write(i, calibrationData[i]); 
    }
}

void loadCalibration() {
    uint8_t calibrationData[22]; 
    for (int i = 0; i < 22; i++) {
        calibrationData[i] = EEPROM.read(i);
    }
    bno.setSensorOffsets(calibrationData);
    Serial.println("Calibration loaded.");
}

void checkIMUCalibration() {  // ✅ setup() 밖에서 함수 정의
    uint8_t system, gyro, accel, mag;
    bno.getCalibration(&system, &gyro, &accel, &mag);
    
    Serial.print("System: "); Serial.print(system);
    Serial.print(" | Gyro: "); Serial.print(gyro);
    Serial.print(" | Accel: "); Serial.print(accel);
    Serial.print(" | Mag: "); Serial.println(mag);

    if (mag < 3) {
        Serial.println("⚠️ 지자계 보정 필요! 센서를 8자(Figure-8) 형태로 회전하세요.");
    } else {
        Serial.println("✅ 지자계 보정 완료!");
    }
}

void clearEEPROM() {
    for (int i = 0; i < EEPROM.length(); i++) {
        EEPROM.write(i, 0xFF);  // 모든 주소를 0xFF(초기 상태)로 변경
    }
    Serial.println("⚠️ EEPROM 초기화 완료! 보정 데이확인터를 다시 저장하세요.");
}

void setup() {
  // clearEEPROM();
  pinMode(kLedPin, OUTPUT);
  Serial.begin(kSerialBaudratePc);
  Serial3.begin(kSerialBaudrateOdrive);
  bno.setExtCrystalUse(true);
  if (!bno.begin()) {
    Serial.println("No BNO055 detected. Halting for safety.");
    while (true);
  }
  delay(1000);

  // loadCalibration();  // ✅ EEPROM에서 보정 데이터 불러오기
  // checkIMUCalibration(); // ✅ 센서 보정 상태 확인

  // PWM decoder interrupt handling.
  attachInterrupt(digitalPinToInterrupt(kSteeringPwmInputPin), SteeringPwmCallbackWrapper, CHANGE);
  attachInterrupt(digitalPinToInterrupt(kThrottlePwmInputPin), ThrottlePwmCallbackWrapper, CHANGE);
  attachInterrupt(digitalPinToInterrupt(kEngagePwmInputPin), EngagePwmCallbackWrapper, CHANGE);

  // Add commands to adjust parameters
  cmd.add_command('q', &SetK_theta, 1, "Set K_theta gain.");
  cmd.add_command('w', &SetKi, 1, "Set Ki gain.");
  cmd.add_command('e', &SetK_theta_dot, 1, "Set K_theta_dot gain.");
  cmd.add_command('r', &SetImuAngleOffset, 1, "Set IMU angle offset.");
  cmd.add_command('t', &SetAdjustmentValue, 1, "Set adjustment value.");
  cmd.add_command('y', &SetScalingFactor, 1, "Set tanh scaling factor.");
  cmd.add_command('a', &SetKpSpeed, 1, "Set kpspeed.");
  cmd.add_command('s', &SetKiSpeed, 1, "Set kispeed.");
  cmd.add_command('d', &SetKdSpeed, 1, "Set kdspeed.");
}

void loop() {

  if (controller_metro.check()) {
    // loop_start_time = micros();
    // 저역통과 필터 적용
  filtered_engage_pwm = kAlpha_2 * engage_pwm + (1.0 - kAlpha_2) * filtered_engage_pwm;
  filtered_throttle_pwm = kAlpha_1 * throttle_pwm + (1.0 - kAlpha_1) * filtered_throttle_pwm;
  filtered_steering_pwm = kAlpha_1 * steering_pwm + (1.0 - kAlpha_1) * filtered_steering_pwm;
    if (motion_controller_enabled) {
      BalanceController();
      // 루프 끝에서 시간 차이 계산 및 출력

      ApplyMotorCommands();  // ✅ 모터에 최종 명령 보내기
  //      loop_duration = micros() - loop_start_time;
  // Serial.print("Loop duration: ");
  // Serial.print(loop_duration);
  // Serial.println(" us");
    }
    
  }
  
  if (print_metro.check()) {
    if (rc_print_enabled) {
      PrintRcSignals();
    }
  }

  if (activation_metro.check()) {    // 지속성 필터링
    if (filtered_engage_pwm > kEngageThresholdPwm) {
      ++engage_signal_persistence;
    } else {
      --engage_signal_persistence;
    }
    engage_signal_persistence = constrain(engage_signal_persistence, -3, 3);
    engage = engage_signal_persistence > 0 ? true : false;
    bool request_motor_activation = engage && !tilt_limit_exceeded;

    EngageMotors(request_motor_activation);

    if (engage && !motors_active) {  
    // Serial.println("Controller engaged. Motors activated.");  // 전원 켜짐 메시지
    } 
    if (!engage && motors_active) {
    // Serial.println("Controller disengaged. Motors deactivated.");  // 전원 꺼짐 메시지
    initialized = false;
    }
    motors_active = engage && !tilt_limit_exceeded;
  }
  // if (led_metro.check()) {
  //   digitalWrite(kLedPin, !digitalRead(kLedPin));
  // }
  cmd.parse_command();
}

// Balance controller implementation.
void BalanceController() {

      // === 1. 버퍼 초기화 ===


  imu::Vector<3> euler_angles = bno.getVector(Adafruit_BNO055::VECTOR_EULER);
  imu::Vector<3> gyro_rates = bno.getVector(Adafruit_BNO055::VECTOR_GYROSCOPE);

  // Update the tilt safety flag based on the latest IMU reading.
  if (abs(euler_angles.y() + imu_angle_offset) > kTiltDisengageThresholdDegrees) {
    tilt_limit_exceeded = true;
    return;
  } else {
    tilt_limit_exceeded = false;
  }

  // Body tilt angle and angular velocity
  theta = imu_enabled * (euler_angles.y() + imu_angle_offset);
  float theta_dot = imu_enabled * (gyro_rates.y());
  float yaw_rate = imu_enabled * gyro_rates.z();

  while (Serial3.available()) Serial3.read(); //엔코더 읽기 전 후 버퍼 초기화
  ///////////////////////////////////////////////////////////////////////

  // === 1. ODrive에서 엔코더 속도 읽기 ===
Serial3.print("j\n"
              "k\n"
              "k\n");

  phi_dot_counts_0 = Serial3.parseFloat();
  phi_dot_counts_1 = Serial3.parseFloat();

  while (Serial3.available()) Serial3.read(); //엔코더 읽기 전 후 버퍼 초기화

  filtered_phi_dot_0 = kAlpha_3 * phi_dot_counts_0 + (1.0 - kAlpha_3) * filtered_phi_dot_0;
  filtered_phi_dot_1 = kAlpha_3 * phi_dot_counts_1 + (1.0 - kAlpha_3) * filtered_phi_dot_1;

// === 2. 실제 선속도 계산 ===
float v_0 = kMotorDir0 * filtered_phi_dot_0 * 2 * PI * kWheelRadius;
float v_1 = kMotorDir1 * filtered_phi_dot_1 * 2 * PI * kWheelRadius;

int steering = kSteeringPolarity * rc_enabled * (filtered_steering_pwm - kSteeringPwmOffset);

// === 3. 컨트롤러 입력 변환 (-1 ~ 1) ===
float throttle_input = (filtered_throttle_pwm - 1491) / ((filtered_throttle_pwm > 1491) ? (1996 - 1491) : (1491 - 980));
float steering_input = (filtered_steering_pwm - 1492) / ((filtered_steering_pwm > 1492) ? (1999 - 1492) : (1492 - 977));

 if (abs(filtered_throttle_pwm - kThrottlePwmOffset) < kControlThreshold) {
    throttle_input = 0;
  }
  if (abs(filtered_steering_pwm - kSteeringPwmOffset) < kControlThreshold) {
    steering = 0;
  }

// === 4. 목표 속도 및 속도 차이 설정 ===
float target_speed = throttle_input * maxspeed;  // 최대 속도 2m/s

// === 5. 속도 제어 (기울기 조정) ===
float speed_error = target_speed - ((v_0 + v_1) / 2.0);
integral_speed_error += speed_error;
integral_speed_error = constrain(integral_speed_error, -kIntegralspeedMax, kIntegralspeedMax);
derivative_speed_error = speed_error - prev_speed_error;
prev_speed_error = speed_error;
float speed_control = kpspeed * speed_error + kispeed * integral_speed_error - kdspeed * derivative_speed_error;
speed_control = constrain(speed_control, -controlspeed, controlspeed);  //

// === 6. 조향 제어 (좌우 속도 보정) ===
float steering_controller = kpSteer * steering + kdSteer * yaw_rate;

  ///////////////////////////////////////////////////////////////////////////////////////

  // === 주행 중 정지 시 초기화 ===
  bool previous_was_driving = was_driving;  // 이전 상태 저장

  if (abs(filtered_throttle_pwm - kThrottlePwmOffset) > kControlThreshold ||
      abs(filtered_steering_pwm - kSteeringPwmOffset) > kControlThreshold) {
    ++drive_signal_persistence;
  } else {
    --drive_signal_persistence;
  }

  // 지속성 필터로 주행 상태 판별
  drive_signal_persistence = constrain(drive_signal_persistence, -2, 2);
  was_driving = drive_signal_persistence > 0 ? true : false;

  if (!motors_active || tilt_limit_exceeded) {
    integral_error = 0.0;  // ✅ 상태에 따라 즉시 초기화
} else {
    integral_error += theta;  // ✅ 초기화된 후에만 누적
    integral_error = constrain(integral_error, -kIntegralMax, kIntegralMax);
}

  float balance_controller = K_theta/100 * theta - K_theta_dot/100 * theta_dot + Ki/100 * integral_error;

  // 기존 토크 입력 계산
  torque_input_0 = (balance_controller - speed_control - steering_controller);
  torque_input_1 = (balance_controller - speed_control + steering_controller);

  // 양수일 때 일정값 추가, 음수일 때 일정값 감소
  torque_input_0 += adjustment_value * tanh(scaling_factor * filtered_phi_dot_0);;
  torque_input_1 -= adjustment_value * tanh(scaling_factor * filtered_phi_dot_1);

  // === 5. 수신된 값 출력 (명칭 없이 값만 출력) ===
  // Serial.print(filtered_phi_dot_0); Serial.print(" ");
  // Serial.print(filtered_phi_dot_1); Serial.println(" ");
  // Serial.print(phi_dot_counts_0); Serial.print(" ");
  // Serial.print(phi_dot_counts_1); Serial.println(" ");
}

void PwmInterruptCallback(unsigned long &last_rise_time, int &pwm_us, int pwm_input_pin) {
  if (digitalRead(pwm_input_pin)) {
    last_rise_time = micros();
  } else {
    pwm_us = micros() - last_rise_time;
  }
}

void ThrottlePwmCallbackWrapper() {
  PwmInterruptCallback(last_throttle_pwm_rise_time, throttle_pwm, kThrottlePwmInputPin);
}

void SteeringPwmCallbackWrapper() {
  PwmInterruptCallback(last_steering_pwm_rise_time, steering_pwm, kSteeringPwmInputPin);
}

void EngagePwmCallbackWrapper() {
  PwmInterruptCallback(last_engage_pwm_rise_time, engage_pwm, kEngagePwmInputPin);
}

void PrintRcSignals() {
  Serial.print(throttle_pwm);
  Serial.print('\t');
  Serial.print(steering_pwm);
  Serial.print('\t');
  Serial.print(filtered_engage_pwm);
  Serial.print('\t');
  Serial.print(engage_pwm);
  Serial.println();
}

// Command functions

void SetK_theta(float value, float foo) {
  Serial.println("Setting K_theta to " + String(value));
  K_theta = value;
}

void SetKi(float value, float foo) {
    Serial.println("Setting Ki to " + String(value));
    Ki = value;
}

void SetK_theta_dot(float value, float foo) {
  Serial.println("Setting K_theta_dot to " + String(value));
  K_theta_dot = value;
}

void SetImuAngleOffset(float value, float foo) {
  Serial.println("Setting IMU angle offset to " + String(value));
  imu_angle_offset = value;
}

void SetAdjustmentValue(float value, float foo) {
  Serial.println("Setting adjustment value to " + String(value));
  adjustment_value = value;
}

void SetScalingFactor(float value, float foo) {
  Serial.println("Setting tanh scaling factor to " + String(value));
  scaling_factor = value;
}

void SetKpSpeed(float value, float foo) {
  Serial.println("Setting kpspeed to " + String(value));
  kpspeed = value;
}

void SetKiSpeed(float value, float foo) {
  Serial.println("Setting kispeed to " + String(value));
  kispeed = value;
}

void SetKdSpeed(float value, float foo) {
  Serial.println("Setting kdspeed to " + String(value));
  kdspeed = value;
}

void EngageMotors(bool request_motors_active) {
  if (request_motors_active != motors_active) {  
    switch (request_motors_active) {
      case true:
        // Serial.println("Engaging motors.");
        odrive.run_state(0, AXIS_STATE_CLOSED_LOOP_CONTROL, false);
        odrive.run_state(1, AXIS_STATE_CLOSED_LOOP_CONTROL, false);
        break;
      case false:
        // Serial.println("Disengaging motors.");
        odrive.run_state(0, AXIS_STATE_IDLE, false);
        odrive.run_state(1, AXIS_STATE_IDLE, false);
        break;
    }
    motors_active = request_motors_active;
  }
}

void ApplyMotorCommands() {  
        // ✅ 모터 전류값 제한
    float current_command_0 = constrain(torque_input_0, -kMaxAbsCurrent, kMaxAbsCurrent);
    float current_command_1 = constrain(torque_input_1, -kMaxAbsCurrent, kMaxAbsCurrent);
    
    // ✅ ODrive 모터에 최종 명령 적용
    odrive.SetCurrent(0, kMotorDir0 * current_command_0);
    odrive.SetCurrent(1, kMotorDir1 * current_command_1);

    // Serial.print(current_command_0); Serial.print(" ");
    // Serial.println(current_command_1);
}

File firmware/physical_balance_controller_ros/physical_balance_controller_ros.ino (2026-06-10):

// Physical self-balancing robot controller with rosserial state publishing.
//
// This sketch is based on firmware/physical_balance_controller/physical_balance_controller.ino
// and adds the ROS communication pattern preserved in archive/arduino_firmware/legacy_balance_controller.ino.
//
// Runtime structure:
// - Arduino keeps the real-time balance, speed, steering, safety, and ODrive current-control loop local.
// - rosserial publishes robot state to ROS as /imu and /odom for visualization, logging, SLAM, or navigation integration.
// - Serial is used by rosserial, so avoid Serial.print debugging while this sketch is connected to ROS.

#include <Wire.h>
#include <Metro.h>
#include <Servo.h>
#include <Adafruit_Sensor.h>
#include <Adafruit_BNO055.h>
#include <utility/imumaths.h>
#include <ODriveArduino.h>
#include <Command_processor.h>
#include <EEPROM.h>

#include <ros.h>
#include <sensor_msgs/Imu.h>
#include <nav_msgs/Odometry.h>

namespace {
// Hardware settings.
constexpr unsigned short kLedPin = 13;
constexpr unsigned short kSteeringPwmInputPin = 2;
constexpr unsigned short kThrottlePwmInputPin = 3;
constexpr unsigned short kEngagePwmInputPin = 19;

constexpr unsigned long kSerialBaudratePc = 115200;
constexpr unsigned long kSerialBaudrateOdrive = 115200;
constexpr int kMotorDir0 = 1;      // Can only be 1 or -1.
constexpr int kMotorDir1 = -1;     // Can only be 1 or -1.
constexpr int kSteeringPolarity = 1;
constexpr int kThrottlePolarity = 1;

// RC settings.
constexpr int kSteeringPwmOffset = 1492;
constexpr int kThrottlePwmOffset = 1488;
constexpr int kEngageThresholdPwm = 1500;
constexpr int kControlThreshold = 50;

// Balance, speed, and steering control parameters.
float K_theta = 24;
float Ki = 0;
float K_theta_dot = 1.7;
float imu_angle_offset = 3.5;
float adjustment_value = 0;
float scaling_factor = 10000;
constexpr float kIntegralMax = 100.0;
float kpThrottle = 0.003;
float kpSteer = 0.001;
float kdSteer = 0.008;
float theta = 0;
float kpspeed = 1.2;
float kispeed = 0.1;
float kdspeed = 7;
float kIntegralspeedMax = 5;
constexpr float controlspeed = 6.0;
constexpr float maxspeed = 1.5;
constexpr float maxSpeedDiff = 0.7;
float integral_error = 0.0;
float prev_speed_error = 0.0;
float integral_speed_error = 0.0;
float derivative_speed_error = 0.0;

constexpr float kWheelRadius = 0.0825;
constexpr float kWheelBase = 0.465;
float phi_dot_counts_0 = 0.0;
float phi_dot_counts_1 = 0.0;
float filtered_phi_dot_0 = 0.0;
float filtered_phi_dot_1 = 0.0;

constexpr float kAlpha_1 = 0.4;
constexpr float kAlpha_2 = 0.02;
constexpr float kAlpha_3 = 1.0;
float filtered_throttle_pwm = 0;
float filtered_steering_pwm = 0;
float filtered_engage_pwm = 1000;
constexpr uint8_t kTiltDisengageThresholdDegrees = 30;
constexpr float kMaxAbsCurrent = 8.0;
float torque_input_0 = 0.0;
float torque_input_1 = 0.0;

// Task scheduling settings.
constexpr unsigned int kBlinkIntervalMs = 200;
constexpr unsigned int kControllerIntervalMs = 0;
constexpr unsigned int kActivationIntervalMs = 50;
constexpr unsigned int kPrintIntervalMs = 50;
constexpr unsigned int kRosPublishIntervalMs = 50;

// State variables.
bool motors_active = false;
bool tilt_limit_exceeded = false;
int engage_signal_persistence = 0;
bool engage = false;

// PWM decoder variables.
unsigned long last_throttle_pwm_rise_time = 0;
unsigned long last_steering_pwm_rise_time = 0;
unsigned long last_engage_pwm_rise_time = 0;
int throttle_pwm = 0;
int steering_pwm = 0;
int engage_pwm = 0;

bool was_driving = false;
bool initialized = false;
int drive_signal_persistence = 0;

// Interactive flags.
bool imu_enabled = true;
bool rc_enabled = true;
bool rc_print_enabled = false;
bool motion_controller_enabled = true;
constexpr bool kSerialGainTuningEnabled = false;

// ROS state.
ros::NodeHandle nh;
sensor_msgs::Imu imu_msg;
nav_msgs::Odometry odom_msg;
ros::Publisher imu_pub("/imu", &imu_msg);
ros::Publisher odom_pub("/odom", &odom_msg);

float odom_x = 0.0;
float odom_y = 0.0;
float odom_yaw = 0.0;
unsigned long last_odom_time_ms = 0;

Adafruit_BNO055 bno = Adafruit_BNO055();
ODriveArduino odrive(Serial3);

// Instantiate Metros for task scheduling.
Metro led_metro = Metro(kBlinkIntervalMs);
Metro controller_metro = Metro(kControllerIntervalMs);
Metro activation_metro = Metro(kActivationIntervalMs);
Metro print_metro = Metro(kPrintIntervalMs);
Metro ros_metro = Metro(kRosPublishIntervalMs);
Command_processor cmd;
}

void saveCalibration() {
  uint8_t calibrationData[22];
  bno.getSensorOffsets(calibrationData);

  for (int i = 0; i < 22; i++) {
    EEPROM.write(i, calibrationData[i]);
  }
}

void loadCalibration() {
  uint8_t calibrationData[22];
  for (int i = 0; i < 22; i++) {
    calibrationData[i] = EEPROM.read(i);
  }
  bno.setSensorOffsets(calibrationData);
}

void clearEEPROM() {
  for (int i = 0; i < EEPROM.length(); i++) {
    EEPROM.write(i, 0xFF);
  }
}

void setup() {
  pinMode(kLedPin, OUTPUT);

  // Serial is used by rosserial in this variant.
  Serial.begin(kSerialBaudratePc);
  Serial3.begin(kSerialBaudrateOdrive);

  bno.setExtCrystalUse(true);
  if (!bno.begin()) {
    while (true) {
      digitalWrite(kLedPin, !digitalRead(kLedPin));
      delay(100);
    }
  }
  delay(1000);

  nh.getHardware()->setBaud(kSerialBaudratePc);
  nh.initNode();
  nh.advertise(imu_pub);
  nh.advertise(odom_pub);

  // PWM decoder interrupt handling.
  attachInterrupt(digitalPinToInterrupt(kSteeringPwmInputPin), SteeringPwmCallbackWrapper, CHANGE);
  attachInterrupt(digitalPinToInterrupt(kThrottlePwmInputPin), ThrottlePwmCallbackWrapper, CHANGE);
  attachInterrupt(digitalPinToInterrupt(kEngagePwmInputPin), EngagePwmCallbackWrapper, CHANGE);

  // Serial gain tuning is kept from the base controller, but disabled by default
  // because rosserial also owns Serial.
  cmd.add_command('q', &SetK_theta, 1, "Set K_theta gain.");
  cmd.add_command('w', &SetKi, 1, "Set Ki gain.");
  cmd.add_command('e', &SetK_theta_dot, 1, "Set K_theta_dot gain.");
  cmd.add_command('r', &SetImuAngleOffset, 1, "Set IMU angle offset.");
  cmd.add_command('t', &SetAdjustmentValue, 1, "Set adjustment value.");
  cmd.add_command('y', &SetScalingFactor, 1, "Set tanh scaling factor.");
  cmd.add_command('a', &SetKpSpeed, 1, "Set kpspeed.");
  cmd.add_command('s', &SetKiSpeed, 1, "Set kispeed.");
  cmd.add_command('d', &SetKdSpeed, 1, "Set kdspeed.");
}
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

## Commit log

2026-04-25 Initial portfolio publish
    [PID.cfg, balence_robot2.urdf, balence_robot_gazebo.xacro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]
2026-04-25 Rename code files for clarity
    [balance_robot.urdf, balance_robot_gazebo.xacro, balance_robot_gazebo_depth.xacro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]
2026-04-25 Use recovered wiring block diagram as primary source
2026-04-29 Polish portfolio docs and ROS workspace
    [PID.cfg]
2026-05-07 recover actual-robot simulation assets
    [balance_robot_urdf.xacro, balance_robot_urdf_depth.xacro, body_side.stl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]
2026-05-28 Finalize portfolio repository cleanup
    [Head_ver2.CATPart, Head_ver2.stl, Head_ver_re1.CATPart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]
2026-10-02 Add files via upload
    트러블슈팅 수정
